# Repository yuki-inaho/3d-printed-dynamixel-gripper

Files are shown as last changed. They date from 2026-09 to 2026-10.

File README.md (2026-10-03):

# 3D Printed DYNAMIXEL Gripper

**2026-10-03 P05改善:** [コネクタ通過窓の局所候補と検査](studies/p05-cable-20261003/README.md)。
凍結V2のコピーへ5.5×10.2 mm・角R0.5の左右窓を反映し、穴と実ケース座面を保持。
モーター取付前の公称コネクタ通過は確認、装着後は後カバー干渉が残る。実物組付け・製作は未承認。
[10手順のグリッパ組立マニュアル](docs/gripper-assembly-20261003/MANUAL.md)には画像・ねじ長さ・個数表を収録。

**2026-09-26取り込み:** [低配置D405のレビュー・OCCT 8再実行](docs/D405_LOW_PROFILE_INTAKE.md)。
俯角30°・爪20 mm延長のV2候補と改善検証器を取り込み、固定Pixi環境でwheel再ビルド・再変換した。
新規URDFと12 STLは受領モデルと全バイト一致。製作承認はfalse。

現行候補: **ID5だけでPG3を開閉、下流の追加モーターなし**。
`outputs/pg3-id5-only-r1/`へ全腕3開度STEP/三面図を生成。原本保持、実機装着DoDは未達。
仕様は[ID5単独開閉](docs/PG3_ID5_ONLY_DESIGN.md)、実行記録は
[Sep24作業書](temp/workdoc_Sep24-2026_pg3_id5_only.md)。

旧r5履歴: **P06局所改修・側方カメラホルダ・取付ねじ候補の6台構成**。
P06/frame干渉240.5625→0 mm3、 nominal離隔0.5 mm。側面4穴だけφ2.8へ変更し、
実相手M06 CADの穴軸・ねじ深さを照合。実機装着・印刷DoDはまだ未達です。
r4ではPG3フレーム端部4箇所だけに0.3 mmの逃げを追加。元部品を再構成せず、
取付穴・主レール・mask外の材料を保持しています。r5では寸法を変えずにクランクの
B-rep生成手順を修正し、simulationも改修済み実組立の形状を使用します。統合CAD/画像/
運動学は`outputs/pg3-installable-candidate-r5/`。r4補足検査は履歴でありr5へ自動継承しません。
[実機装着の受入状況と未確定条件](docs/INSTALLATION_READINESS.md)を参照してください。
[旧r5の設計契約・締結・組立順・再現方法](docs/PG3_INSTALLATION_CANDIDATE.md)は履歴です。
[以前の無改修取込結果](docs/PG3_C9_INTEGRATION.md)は比較用の履歴です。

2026-09-23再監査: **全DoD達成の宣言は撤回**。ラック案は歯・案内・固定が未実装の概念図。
PG2 R5 (縦置きXL430、クランク+2リンク、印刷ガイド) を別候補として追加しました。
[辛口レビュー・2方式の現状と改善順](docs/REVIEW_PG2_AND_SELF_AUDIT.md)を先に参照してください。

2026-09-24の要求は、**全XL430・ロール不要・平行グリッパ**です。
ID5だけで開閉・追加モーターなしに確定。旧r5は最新要求の完成形ではありません。
[新設計仕様](docs/PG3_ID5_ONLY_DESIGN.md)と
[作業書](temp/workdoc_Sep24-2026_pg3_id5_only.md)に沿って検証中です。
カメラ未購入、28x28 mm四穴を維持。最新希望はID5モーターケース角ねじ付近を使い、
モーター上方から把持域を斜め下向きに見る構成です。旧P05側方案は受入候補ではありません。
詳細は[新カメラ取付要求](docs/CAMERA_MOUNT_ID5_CORNER.md)と
`specs/camera_mount_id5_corner.yaml`を参照。把持物は寸法未定のキューブ。
P05局所配線逃げ候補の検討は許可済みですが、CADは製作承認ではありません。
コード位置と再現用CAD入力は[カメラ設計コード索引](docs/CAMERA_MOUNT_CODE_INDEX.md)にまとめています。

- [カメラジグの設計・検証・組立順序](docs/CAMERA_JIG.md)
- [全XL430末端の現状と検証結果](docs/ALL_XL430_TERMINAL_STATUS.md)
- [BOM草稿](docs/BOM_DRAFT.md)
- [組立・合成校正・実機校正の手順](docs/ASSEMBLY_AND_CALIBRATION.md)
- [未解決事項と再開条件](docs/OPEN_ISSUES.md)
- [他エージェントの横開きグリッパ・カメラ案のレビューと改善方針](docs/REVIEW_LATERAL_20260922.md)
- カメラCAD: `outputs/camera-jig-20260922-r11/`。
- 全XL430末端CAD: `outputs/terminal-all-xl430-20260922-r3/`。
- MuJoCo/AprilTag E2E: `outputs/calibration-demo-20260923-r4/`。
- いずれも **UNVALIDATED/診断候補。印刷・実カメラ校正・運用承認ではない。**

```bash
rtk proxy uv sync --locked
rtk proxy env MUJOCO_GL=egl uv run pytest -q -n auto --dist loadgroup   # 並列（推奨）
rtk proxy env MUJOCO_GL=egl uv run pytest -q                              # 逐次（同じテスト集合）
rtk proxy env MUJOCO_GL=egl uv run python -m scripts.review_pg3_installation \
  --out outputs/pg3-install-next
rtk proxy uv run python -m scripts.review_pg3_guide_relief outputs/pg3-install-next \
  --out outputs/pg3-install-next-audit/guide_relief
```

並列実行の振り分けは `tests/conftest.py` が決める（モジュール単位、重いモジュールは分割、合成キャリブレーションは1回生成）。
繰り返し解析するSTEPは `.pytest_cache` の内容アドレス型キャッシュから読む（`CAD_STEP_CACHE_DIR=` で無効化）。
i7-9750H（6コア/12スレッド）で719件: 12並列約1分50秒、6並列約2分15秒、逐次約5分30秒（変更前14分06秒）。12並列の最小空きメモリ約9 GB。
内訳と判断は [テスト実行時間の記録](docs/TEST_PERFORMANCE.md)。検証対象・閾値は逐次実行と同一。

現在の生成・監査は未達項目を残すためexit 2。正常終了や描画だけを印刷承認にしません。
原本01_frame/07_crankのコピーは参照用で、r5の部品選択は`review.json`のreplacement mapに従います。

以前のカメラ単体・校正デモを再現する場合 (現PG3統合版とは別):

```bash
rtk proxy uv run python -m camera_jig.build --out outputs/camera-jig-next
rtk proxy uv run python -m camera_jig.serviceability outputs/camera-jig-next
rtk proxy env MUJOCO_GL=egl uv run python scripts/run_calibration_demo.py \
  --config specs/simulation_calibration.yaml \
  --out outputs/calibration-demo-next
```

出力先は未使用のrun名にする。`camera_jig.serviceability`は、装着状態でカメラねじへ工具が
入らないことを検出してexit 2になる。先付け工程の結果は同JSON内で別に記録する。
静的合格を可動域・強度・配線・印刷承認へ読み替えない。

PG2の入力検証・独立STEP検査 (元ソースは実行しない):

```bash
rtk proxy uv run python -m scripts.review_pg2 import \
  outputs/PG2_XL430_upright_printed_guide_R5.zip --out references/pg2-r5
rtk proxy uv run python -m scripts.review_pg2 review \
  --source references/pg2-r5/PG2_XL430 --out outputs/pg2-next --render
```

この環境では取込済み。importは既存ディレクトリを上書きしません。
reviewは全腕未適合・未解決を理由にexit 2。JSONと画像は残し、成功扱いで印刷へ進めません。
方式台帳: `specs/gripper_variants.yaml`。最新診断: `outputs/pg2-independent-20260923-r2/`。
旧E2E r4は履歴であり、コード変更後のSHA再検証で不一致になることは正常です。

## 構成

- `camera_jig/`: P05固定カメラジグの生成/検証コード。
- `gripper_design/`: 全XL430 interface、平行ジョー概念、末端assembly、締結/工具契約。
- `simulation/`: 座標変換、AprilGrid、MuJoCo EGL描画、検出、校正、CAD連携。
- `tests/`: 正常・不良対照の回帰検査。
- `references/arm-r3/`: 写真のリンクに対応するR3入力。変更禁止。
- `references/robonine/`: SO101参考カメラ取付とライセンス。
- `skills/`: プロジェクト内のコピー。PlaywrightはCADスキルと独立。
- `references/arm-baseline/`, `references/prior-checkpoint/`: 別形状・旧調査。今回の取付元と混同しない。
- `docs/HANDOFF.md`, `REQUIREMENTS.md`, `DESIGN_BASIS.md`, `INTERFACES.md`,
  `CAD_PDCA.md`: 初期引継ぎ資料。PG3最新状態は`PG3_INSTALLATION_CANDIDATE.md`を優先する。
- `outputs/`, `temp/`: Git対象外。検証結論はdocsにも記録。

Python 3.12 + uv。GitHubリポジトリは`yuki-inaho/3d-printed-dynamixel-gripper`。
CAD作業中の実機通電・通信・モーター制御は行わない。

## Onshape取り込み・検証・URDFの保存点

[2026-09-26の成果と手順](studies/onshape-20260926/README.md)。短縮D405候補の公開V2、URDF、スクリーンショット付きマニュアル、作業記録を保存。次の低位置カメラ・爪延長設計の比較基準です。

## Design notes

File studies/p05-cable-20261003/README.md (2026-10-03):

# P05コネクタ通過窓の局所改善候補

2026-10-03。ユーザーの「コネクタ付きでも通せる寸法」という条件に合わせ、
凍結Onshape V2のP05左右窓を **5.5×10.2 mm、四隅R0.5 mm** に変更した。
Chili3Dで確認したコピーを保存し、元V2、他261部品、モーターケースは保持した。
実物組付けと製作は未承認。**コネクタの窓通過はモーター取り付け前の診断であり、
取り付け後にコネクタを直線で抜き差しできる判定ではない。**

## 成果物

- [統合STEP](CAD/V2_P05_CABLE_CLEARANCE_CANDIDATE.step)
- [P05単体STEP](CAD/P05_CABLE_CLEARANCE_CANDIDATE.step) / [STL](CAD/P05_CABLE_CLEARANCE_CANDIDATE.stl)
- [P05単体の窓](images/view-support.png)、[右側とモーター](images/view-motor-right.png)、[左側とモーター](images/view-motor-left.png)、[支持の斜視](images/view-oblique.png)
- [CAD検査結果](evidence/review.json)、[静的接触走査](evidence/contacts.json)、[装着後コネクタ通過の診断](evidence/plug-with-motor-diagnostic.json)
- [全262部品の保持照合](evidence/unchanged-occurrences.json)、[Chili3D読込・入力SHA](evidence/browser-p05-cable-check-20261003.json)
- [保存後のSHA・文書リンク・ブラウザ検査](evidence/final-verification.json)
- [グリッパ組立マニュアル](../../docs/gripper-assembly-20261003/MANUAL.md) / [PDF](../../docs/gripper-assembly-20261003/MANUAL.pdf)
- [設計判断・検証記録](WORKLOG.md)、[保存ファイルのSHA](MANIFEST.json)

## 寸法と変更範囲

単位mm。窓中心は元V2 world座標Y=151.15、Z=178.7。
左右の既存側壁を貫通し、側壁厚4 mm、内側面X=-14.45/+14.05は移動しない。

| 項目 | 元V2 | 改善候補 |
|---|---:|---:|
| 配線窓の幅Y×高さZ | 3×8 | 5.5×10.2、角R0.5 |
| 仮線φ1.9からP05までの最小距離 | 0.55 | 1.65 |
| 仮線から後カバーまでの最小距離 | 0.25 | 0.25 |
| EHR-3公称筐体の窓通過（モーターなし） | 干渉56.126 mm³/側 | 最小距離0.35 |
| ケースを挟む内側面間隔 | 28.5 | 28.5 |
| 実ケースとの接触面積（各側） | 942.005 mm² | 同じ材料セット、lost/added=0 |
| 元の円筒穴面 | 18 | 18、位置・径・範囲を保持 |
| 窓mask外／保護領域の材料損失 | — | 0 / 0 mm³ |
| 局所除去体積 | — | 270.535 mm³ |

検査に用いたEHR-3筐体断面は9.5×3.8 mm、通過向きは9.5をZ、3.8をYに合わせる。
高さ6.5と別の0.6突出を含む保守的な軸方向包絡を使った。
実ケーブルのロック部・被覆・曲げ制限・造形公差は未確認であり、この公称値を実物保証にしない。
配線診断はPCBから内部で90度曲げ、側方へ直線で出す仮経路である。
PCBヘッダーの軸方向に後カバーを貫く経路は採用していない。

## 組付けの条件と残る問題

モーターが入る前にコネクタをP05窓へ通すことを候補の前提とする。
先配線したモーター全体の挿入軌跡は未検証なので、実行済みの組立手順として扱わない。
モーターを置いた状態でコネクタを側方へ直線移動すると、左右とも後カバーと約29.43 mm³干渉する。
このFAILは窓を広げた結果にも残る。カバーを削る／外したまま使う解決は行っていない。

P05・仮線・全保存相手を除外なしで走査した1848組は **1841 PASS / 1 ERROR / 6 UNKNOWN**。
ERRORは`088:ARM_M04_ref00`の供給B-repのBoolean自己対照不成立、UNKNOWNは仮線6本と
非solidの`152:ARM_M05_ref05`の重なり。これらを組付けPASSへ読み替えない。
装着後プラグ診断524組は **518 PASS / 2 FAIL / 2 ERROR / 2 UNKNOWN**。
FAILは`157:ARM_M05_ref06`後カバー、ERRORは`143:PG3_XL430_fixed`、UNKNOWNは同非solid参照。

接触面保持は締付け荷重・支持強度・印刷嵌合の合格ではない。
実ハーネス、曲げ、ストレインリリーフ、ねじと工具、先配線モーター挿入、全腕可動中の配線は未確認。
CADのM05ラベルと実機ID5の対応観測も未確定のまま。

## 入力と再現

入力は[凍結V2 STEP](../low-profile-20260926/outputs/low-profile-250g/CAD/final-version.step)。
SHA-256: `9f58c947753e9229b30939da23ce4c87c1cc85eeb39372518de4ffb98991b93f`。
[元Onshape V2](https://cad.onshape.com/documents/29e8557c76e89bcf64f50566/v/f6162b4adc88af9d07f1194a/e/d5415bf725ba822741b01703)を変更せず、
XCAFのP05だけをコピー上で置換した。Onshapeクラウド文書、URDF、G-codeは更新していない。
262 occurrenceの名前・階層・配置を保持し、他261部品の形状署名を照合した。
この署名検査を不良B-repの完全な材料集合同等性の証明にはしない。

```bash
rtk proxy uv run --no-sync python -m scripts.review_p05_cable_clearance --out outputs/p05-cable-next
rtk proxy uv run --no-sync pytest -q tests/test_p05_cable_relief.py tests/test_p05_cable_clearance.py
rtk proxy uv run --no-sync ruff check gripper_design/p05_cable_clearance.py scripts/review_p05_cable_clearance.py tests/test_p05_cable_clearance.py
```

変更対象の既存9＋新規14＝23試験PASS。全リポジトリのsuiteは未実行。
STEP再読込のP05材料対照、単体STLの閉じた1成分、実ケースのtrim済み面接触を検査した。
CAD依存版はreview.jsonと既存uv.lockに記録している。
公式経路は[ROBOTIS XL430組立説明](https://emanual.robotis.com/docs/en/dxl/x/xl430-w250/#idler-horn-assembly)、
公称コネクタ寸法は[JST EHデータシート](https://www.jst-mfg.com/product/pdf/eng/eEH.pdf)を参照した。

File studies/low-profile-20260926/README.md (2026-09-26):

# 低位置D405・爪延長スタディ

**今回の取り込み:** [レビュー・Pixi/OCCT 8再実行](../../docs/D405_LOW_PROFILE_INTAKE.md)。
固定lockからwheelを再ビルド・再変換し、保存V2との全バイト一致を確認した。
個人パスを除いたテキストと新しいSHA一覧は `integration/` を参照。
以下の「今回」は受領した各記録の実行時点を指す。

**引き継ぎ継続:** [検証器改善・実STEP再検証](revalidation/README.md)。
旧D6/D7を保存証跡として監査し、52試験と独立STEP再読込を追加した。
CAD/URDF形状は未変更。以下の35試験は前回の記録であり、今回の52件と混同しない。
`revalidation/` を保存範囲に追加した。元の327件一覧は同ディレクトリのINPUT-SNAPSHOT-MANIFESTに保持する。

2026-09-26、俯角30°、爪+20 mm、D405ガラス中心(-0.2,165,235) mmを選定。旧75°候補に比べカメラ高さは12.40 mm低い一方、250 gとカメラ等の部分モーメントは9.45%増える。V2から新規URDFを生成し、441閉路と11native姿勢を検証した。実物の耐久性・材料・造形・校正は未確認。

- [20ページ操作マニュアルPDF](outputs/low-profile-250g/MANUAL.pdf) / [画像拡大可能なHTML](outputs/low-profile-250g/MANUAL.html) / [設計比較レポート](outputs/low-profile-250g/REPORT.md)。
- [最終URDFと再現方法](outputs/low-profile-250g/robot/README.md)、[作業書](outputs/low-profile-250g/WORKDOC.md)、[保存情報](outputs/low-profile-250g/DELIVERY.md)。
- [公開Onshape V2](https://cad.onshape.com/documents/29e8557c76e89bcf64f50566/v/f6162b4adc88af9d07f1194a/e/d5415bf725ba822741b01703)：左右パッドの所属を修正した版。
- [設計選定](outputs/low-profile-250g/SELECTION.md)、[UI検証](outputs/low-profile-250g/NATIVE-VALIDATION.md)、[出力記録](outputs/low-profile-250g/EXPORT.md)。
- [変換器](https://github.com/yuki-inaho/urdf_from_step/tree/codex/pixi-occt8)：commit `1b2cea3`、Pixi + OCCT 8.0.1、13回帰試験PASS。新モデルのFK/負対照4件とCAD18件を合わせ35試験PASS。
- [リポジトリ直下skills/の4スキル](../../skills/ONSHAPE-WORKFLOW.md)：Onshapeの実証知見、write/review/startと全参照ファイルを保存。

`CAD/final-version.step` が修正版V2の入力。`diagnostics/v1-pad-misassigned` は負の証拠として保存した旧失敗例であり、製作用データではない。標準UI URDF ZIPも旧V1の参考出力である。

保存範囲は `outputs/low-profile-250g` と `work/low-profile` のみ。SHA256は `SNAPSHOT-MANIFEST.json`。秘密情報の既知パターンをZIP内も含め検査し、ブラウザプロファイル、認証状態、HTTPキャッシュ、bytecodeは含めない。スクリプトは当時のディレクトリ構造と元リポジトリのuv環境に依存するため、コピーだけで全操作を再実行できる独立パッケージとはしていない。UI更新スクリプトを公開保存版へ無条件に再実行しない。

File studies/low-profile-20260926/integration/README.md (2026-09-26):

# 今回の取り込み・Pixi/OCCT 8追試

[取り込みレビュー](../../../docs/D405_LOW_PROFILE_INTAKE.md) と [verification.json](verification.json) が
今回の記録。隣の `revalidation/` は受領した別エージェントの記録であり、別実行として保持する。

## 元環境の追試

repo rootから実行する。Linux用の固定lockを使い、既存の出力を上書きしない。
以下の変換はCADファイルを読み、ローカルファイルを作る。Onshapeへのアクセスは不要。
Git取得と依存パッケージの取得にはネットワークが必要。

```bash
RUN=$(mktemp -d temp/d405-occt8-XXXXXX)
CONVERTER="$RUN/converter"
BASE=studies/low-profile-20260926/outputs/low-profile-250g
rtk proxy git clone --single-branch --branch codex/pixi-occt8 https://github.com/yuki-inaho/urdf_from_step.git "$CONVERTER"
rtk proxy git -C "$CONVERTER" checkout --detach 1b2cea31c56b875bf98c1d65084781322f5fc835
rtk proxy pixi install --manifest-path "$CONVERTER/pixi.toml" --locked
rtk proxy pixi run --manifest-path "$CONVERTER/pixi.toml" --locked versions
rtk proxy pixi run --manifest-path "$CONVERTER/pixi.toml" --locked test
rtk proxy pixi run --manifest-path "$CONVERTER/pixi.toml" --locked build
PY="$CONVERTER/.pixi/envs/default/bin/python"
rtk proxy "$PY" -I -m pip install --no-deps "$CONVERTER/dist/urdf_from_step-0.2.0-py3-none-any.whl"
rtk proxy "$PY" -I -m urdf_from_step "$BASE/CAD/final-version.step" --config "$BASE/robot/converter-config.json" --output "$RUN/model"
rtk proxy uv run --no-sync python "$BASE/robot/replay_step.py" --output "$RUN/replay"
rtk proxy "$PY" "$BASE/robot/validate_robot.py" --model "$RUN/model" --native "$RUN/replay/native-pose-transforms.json" --output "$RUN/verification.json"
```

`python -I` でソースツリーのPYTHONPATHを除外し、インストールしたwheelを用いて変換する。
kernelはPixiのOCCT 8.0.1配布バイナリであり、OCCTソース自体の再コンパイルではない。
CadQuery/OCPで行うSTEPの独立読込はrepoのuv環境を使う。
CLIの生ログには環境のパスが出るため、`RUN` はGit対象外に置く。

## 証跡の読み方

- `verification.json`: D6保存監査・D7実行の区別、archive SHA、kernel/wheel情報、結果、未確認項目。
- `kinematics.json`: 新規OCCT 8変換と今回の独立STEP再読込の照合。
- `native-pose-transforms.json`: 今回の11姿勢の独立読込から作った入力。
- `converter-tests.xml`: 今回の変換器13試験。
- `robot-tests.xml`: 取り込み・修正後の改善版52試験。
- `cad-tests.xml`: 保存検査補強後の20試験。変更前の18件に2件追加。
- `geometry-preservation.json`: 保存された実V2の爪/パッドとR5原本の照合。
- `artifact-equality.json`: 新規URDF/config/12 STLと受領した最終V2の全バイト一致。
- `quality.json`: lint・プライバシー照合と、既存19ファイルの整形不一致。
- `manifest.json`: 共有可能な取り込みファイルの最終SHA。元manifestの代わりに検査する。

取り込み時にテキストの個人パスを除去したため、元の `SNAPSHOT-MANIFEST.json`、
`INPUT-SNAPSHOT-MANIFEST.json`、旧XML/JSON内のSHAは原本に対する履歴である。
元bundleは取り込み前に1599件の全ファイル照合がPASSした。原本はGit対象外で保管する。
このディレクトリのログも個人パスを除いた写しであり、バイト同一の生ログとは呼ばない。

生成モデルは受領モデルと全バイト一致したため、同じ大きなSTLを二重にGitへ追加しない。
新規生成モデル・wheel・生ログ・各姿勢の完全inventoryはローカルの
`temp/intake_d405_20260926/occt8-original/` に残す。

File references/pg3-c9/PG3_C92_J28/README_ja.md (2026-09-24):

# C92-J28 — 小型の駆動部に、把持面の広い爪を組み合わせる改訂

版: PG3-C92-XL430-J28-C9 / 作成: 2026-09-23

**CAD上の試作検査を完了。印刷・実組立・摩擦・把持力・強度・摩耗は未検証です。**

## 変更の要点
前案は全奥行62 mmを優先し、爪と接触パッドを短くしすぎました。今回は本体の小型化を維持し、爪の前方への張り出しと連続した把持面を増やしました。

| 寸法 | C7 | C92-J28 |
|---|---:|---:|
| 全幅 | 92 mm | 92 mm |
| 全高 | 63.25 mm | 63.25 mm |
| 爪の前後長 | 12.1 mm | 28 mm |
| 爪の高さ / 板厚 | 36 / 5 mm | 36 / 5 mm |
| パッドの高さ×奥行×厚さ | 28×3×1 mm | 28×20×1 mm |
| 案内シューの移動方向の長さ | 14 mm | 18 mm |
| 最大開口（左右1 mmパッド込み） | 48.895 mm | 48.895 mm |
| 閉位置の開口 | 0.927 mm | 0.927 mm |
| サーボ背面から爪先まで | 61.8 mm | 77.7 mm |

爪は単純に拡大していません。穴位置・座面をそのままに、根元へ補強リブを追加し、把持面の貫通窓をなくしました。パッド全域に5 mm厚の裏打ちがあります。
上下のシューは中央側へ4 mm延長しました。クランクを避けるため、延長部分の内縁には0.5 mmの逃げを設けています。閉じ位置の左右スライダ最短距離は1.927 mmです。

## 変更しないもの
単一XL430-W250の背面直立配置、枠、押さえ、クランク、リンク、ホーンスペーサー、元の締結品と穴位置です。金属の案内棒・別体の金属カラー・直動軸受はありません。通常ねじ・ナット・座金は既存どおり使用します。カメラと全腕接続は対象外です。

## 納品内容
- CAD/C92_J28_open.step、mid.step、closed.step: 名称付き組立CAD。世界Xが開閉、Zが上、-Yが前です。
- STL/changed_parts/: 左右スライダと左右爪の4個。すべて各1個です。
- STL/unchanged_C7/: 基本形状を変更していない残りの部品。新規製作時は全部で9種類11個です。
- CAD/parts/: 部品STEP。これは構築座標であり、印刷姿勢や組立移動位置とは別です。
- REVIEW_ja.html、docs/: 設計・作業・組立・現物受入資料。
- reports/: この版で実行した結果。iterations/C8には距離不足で不合格だった前段の記録。
- source/: 再生成と検査。reference/C7は使った旧版ソースとサーボ模型であり、現物保証ではありません。

## 実行したCAD検査
56件の旧版形状・配置照合、1,101点の運動拘束式、25〜135°を0.5°刻みで221姿勢の全組立干渉、45姿勢の変更部接近距離を確認しました。不許可の交差体積が0.01 mm³を超える組合せは0件です。指定嵌合・同一剛体群の締結を除いた、変更部を含む組合せの最小測定距離は0.400 mmです。クランクと延長シューには95〜125°を0.1°刻みで追加検査しました。
工程別挿入9経路・工具軸18件、標準9 STL・3組立STEPの再読込みが合格です。6種類の意図的な誤形状も拒否しました。
10/25/45 mm幅の箱と直径25 mmの円柱が両パッドに接触し、前方の経路で他部品と交差しないことを検査しました。把持面全域の裏打ちも体積で検査しています。これは物体保持の試験ではありません。

## 荷重をどう扱ったか
爪が長いほど同じ力でも案内部へのモーメントが増えます。5 N/爪を仮の計算点とすると、パッド中央で旧約107.5 Nmmから新139.5 Nmmへ増えます。先端寄りでは189.5 Nmmです。
支持長を内側へ延ばして荷重を受ける距離を広げましたが、それで摩擦・強度が保証されるわけではありません。reports/load_review.jsonの反力・摩擦・単純梁の値は、明記した仮定による計算例です。実測の材料特性や摩擦係数を使った有限要素解析ではありません。5 Nは耐荷重でも定格でもありません。
接触面が広いことは、保持力が面積比例で増えるという意味ではありません。設計の目的は、物を差し込む深さと接触位置の選択肢を確保することです。

## 再生成
requirements.txtの環境を用意し、source/rebuild.pyを実行します。旧版のレポートを再利用せずにCAD・検査・画像・レビューを再生成します。実機へ指令を送るコードは含みません。

## 出典と区別
元の機構構成は会話中のMini Max作例を参照しました。今回の28 mm、18 mm、78 mm上限はこの改訂の設計判断であり、元記事の寸法ではありません。
案内の荷重点・支持間隔について参考にしたメーカー説明は igus「The 2:1 Rule and How to Define Fixed and Floating Bearings」です。その製品固有の2:1数値を、この印刷ガイドの合格基準として移植していません。
https://www.igus.com/company/linear-guides-the-2-1-rule-ca
サーボの制御情報: https://docs.robotis.com/docs/dxl/model_reference/x_series/xl_series/xl430-w250/

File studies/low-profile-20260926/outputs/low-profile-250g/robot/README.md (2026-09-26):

# V2 STEPから生成した運動学モデル

**継続作業の改善:** [52試験と独立STEP再読込](../../../revalidation/README.md)。
`validate_robot.py --model outputs/model --output outputs/new/report.json` で対象を明示できる。
引数なしでは保存modelを検査して標準出力へ表示し、下記の過去validation.jsonは上書きしない。
`replay_step.py --output outputs/new/replay-directory` がSTEP本体を再読込する。
元のPixi/OCCT8変換と、今回のCadQuery/OCP独立検査は別の実行記録である。

- 最終URDF: [model/robot.urdf](model/robot.urdf)、12 STLは [model/assets](model/assets)。一式を同じ相対配置で扱う。
- 関節設定: [converter-config.json](converter-config.json)、元のUI定義 [joint-definitions.json](joint-definitions.json)。
- 閉路の従属計算: [pg3_states.py](pg3_states.py)。`python pg3_states.py 25` で開、90で中立、135で閉。
- 照合: [validation.json](validation.json)、[validate_robot.py](validate_robot.py)、[test_validation.py](test_validation.py)。
- 再現環境・コマンド: [CONVERTER.md](../CONVERTER.md)。Pixi + OCCT 8.0.1、ROSなしで実行。

16リンク/15関節、5能動+4受動+6固定。閉路は左右それぞれ2つの固定補助frameの位置一致で検証する。441状態と11 native姿勢を照合済み。入力は `../CAD/final-version.step`（V2、SHA256 `9f58c947753e9229b30939da23ce4c87c1cc85eeb39372518de4ffb98991b93f`）。部品262件を12メッシュへ新規変換した。

このモデルは運動学用。effort/velocity=0は未設定であり、コントローラ設定として使わない。質量/慣性、実機ホーム、カメラ外部校正、物理エンジン用collision形状は未確定。`onshape-native/` は修正前V1の比較用出力で、最終モデルではない。

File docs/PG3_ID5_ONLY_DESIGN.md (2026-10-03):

# ID5単独開閉 PG3 設計仕様

2026-10-03局所候補: [P05コネクタ通過窓](../studies/p05-cable-20261003/README.md)。
凍結V2コピーで左右窓5.5×10.2 mm・角R0.5、既存穴と実ケース座面を保持。
ユーザー条件はコネクタ付き通過。モーター取付前の公称筐体通過だけを確認し、
装着後の後カバー干渉、先配線モーター挿入、実物対応・製作ゲートは未達のまま。
下記の支持・配線・締結要求を置き換えない。

更新: 2026-09-24。状態: 設計・検証中、製作未承認。
作業手順と実績は `temp/workdoc_Sep24-2026_pg3_id5_only.md`。
本書は「何をどの構造で満たすか」を定義し、実行済み判定とは分ける。

## 1. 目的と確定要求

既存全XL430アームへPG3平行グリッパとカメラを装着できる状態にする。
ID5のXL430-W250-T一台で開閉する。手首ロール用の別モーターや追加ID6は使わない。
既存ID1〜4を消したり、ロール機構を残して単にソフト固定する解釈は採用しない。
カメラは未購入、SO101参考と同じ28x28 mm四穴を維持する。最新要求はID5モーターの
ケース角ねじ付近で支持し、モーター上方から把持域を斜め下向きに見ること。
旧P05側方マウントは視点が意図に合わず、新候補の採用案ではない。
対象は寸法/重量未定のキューブ。10/20/30 mmは比較用提案であり確定仕様ではない。
P05の局所配線逃げ候補と再印刷案は許可済み。原本/穴/締結・接触面/支持機能を保持。
付属M2.6x5ねじはない/不明。型番/頭/ねじ山/先端/有効深さを検証せず代用品を決めない。
実印刷・SD書込・通電・シリアル操作・購入は本作業では行わない。

## 2. 旧設計との相違

| 項目 | 旧r5 | 新候補 |
|---|---|---|
| ID5の役割 | ロール候補 | 開閉専用、ユーザー確定 |
| 末端駆動台数 | ロールと開閉の2台 | 開閉の1台 |
| PG3配置 | CAD M06位置 | CAD M05位置を幾何候補とする |
| P06/元P07 | P06局所改修を保持 | 下流モーターと共に撤去候補 |
| P05 | 未変更 | 支持機能維持、必要な配線逃げだけを別版で検討 |
| カメラ | P05固定の側方支持 | ID5モーターケース角ねじ付近に支持する頭上・斜め下向き候補 |
| 可動評価 | 追加ロール±30度を含む | ID4等上流姿勢と開閉。独立ロールなし |

ユーザーが確定したのは役割と台数。CADのM05という文字列が実機ID5の実測証拠にはならない。
次節の配置は新設計の採用候補であり、非通電実物照合ゲートは残す。
元r5を上書きせず、新しい出力ディレクトリと部品台帳を使用する。

## 3. 座標・配置契約

単位mm。アームは `references/arm-r3/arm_XL430_R3.step` の保存world座標。
PG3内部座標はX=開閉方向、Y=機構上方、Z=出力軸/指の延長方向。
候補変換は `world = Rx(-90deg) * local + (-0.2,164.9,164.6)`。
これによりZ出力軸はworld +Y、爪の開閉方向Xはworld Xになる。
供給モーターSTEPをこの変換で置き、元M05_ref00に有限形状署名を照合する。
さらに実取付穴/座面を照合する。署名一致だけで完全材料同等性やboltabilityを承認しない。

部品帰属契約:
- M01〜M04とP01〜P05等の上流部品は保存する。
- M06配下全要素、P06、P07を新候補の撤去台帳へ記録する。原本からは削除しない。
- M05_ref00はPG3のfixed/horn分割表示へ置換する。他のM05参照は原位置で保持する。
- 分割fixed/hornの2 CAD要素は物理モーター1台。隠れた2台目を許容しない。
- 新カメラ候補はID5モーターの固定ケース側へ支持し、開閉ホーンには固定しない。
  ケース角ねじが適切な取付点かは未確認。元CADのM05ラベルも実機ID5との観測照合を証明しない。
- 角度はPG3機構角25〜135度。実XL430絶対角/ホーム値との対応は未確定。

## 4. 支持・配線・締結

新配置ではID5ケースをP05が支持し、出力ホーンがPG3クランクを駆動する。
PG3フレームはケースに固定する。原P05とフレームの干渉があれば、P05の支持を
削って通すのではなく、重複する固定構造・ねじ・荷重経路から再設計する。
無断の支持幅変更や嵌合面移動、旧P06を非表示にするだけの浮遊組立は禁止。

配線は公式ケース出口/中空軸を起点とする。ケーブル断面/曲げ径は実品未確定。
既存のOD1.9/R1.2診断は製品保証値でなく、これだけで最小窓寸法を決めない。
窓候補ごとに変更mask・除去体積・保護面・最小残断面・丸み・組付順を記録する。
case cover内部の交差はP05を削っても解消しないため別扱いとする。
挿抜/先配線/最終配線状態/開閉時の屈曲を分離して検査する。
支えの連結性はCAD、PLA強度/クリープは荷重/材料/印刷条件と実物で検証する。

初期配線窓の比較候補: 左右の厚4mm側壁のみ。X[14.05,18.05]と[-18.45,-14.45]を
貫通し、YZ平面で中心線Y151.0、端部中心Z176.2/181.2、端部R1.5の丸長穴。
窓の幅3.0/全高8.0mm。旧診断OD1.9に対する側壁通過の名目隙間は0.55mm。
これは曲げ許容/プラグ通過/実ケーブルの最小寸法決定ではない。
穴中心群と元穴外周2.5mmの保護環、Y144.4以下のクランプ/連結板を切除しない。
原motor接触面の変化と荷重成立は別評価する。切除率だけで強度合格にしない。
この候補を新アームへ自動採用せず、単体・全体差分・配線残交差を保存する。
初案Y150.6は仮ケーブルがmotor rear coverに6箇所交差したため棄却。
Y151.0は線径/曲率/モーターを変更せず、側方脚と窓位置だけ0.4mm移動する候補。
仮ケーブル対カバーの公称隙間0.25mmを別検査する。実ケーブルの曲げ許容は未確認。

## 5. カメラと対象

取付ピッチは28x28 mm四穴で、基板外形やFOVではない。旧仮FOV50度は診断限定。
視点はID5ケース角ねじ付近の支持から、モーター上方を通して把持域へ斜め下向きに向ける。
角度や突き出し量は未決で、CAD上の視野比較を先に行う。旧P05側方位置を少し動かすだけで
要求を満たしたとしない。カメラの型番・実外形・光学中心・FOV・重量はnullのまま扱う。
キューブの実寸未定なのでまず10/20/30 mmの比較画像と遮蔽物帰属を出す。
画像に一画素でも見えることを実用可視性としない。キューブと指、パッドの遮蔽を分ける。
取付位置変更はカメラ実体/ホルダ/工具/ケーブルも追従させる。仮想センサだけを移動しない。
ケース角ねじの用途、ねじ長/有効かかり/ケース締結維持、頭への工具アクセス、組立順と
カメラケーブル経路を同じ候補版で調べる。これらが未解決なら取付・印刷承認を出さない。
候補型番/焦点/質量は `docs/CAMERA_SELECTION.md`。未購入でも設計作業は継続する。

## 6. 実装境界

新規 `gripper_design/pg3_id5.py` が配置/帰属を担当する。
`scripts/review_pg3_id5.py` が保存・再読込・対検査・画像・証跡を担当する。
既存 `gripper_design/pg3.py` の運動学と `pg3_crank_representation.py` の修正を再利用。
旧配置の `pg3_installation.py` は再現用として残す。
`simulation/pg3_scene.py` は既存配置を既定値として保ち、明示的なno-roll配置を追加する。
変更後のPG3実体を逆変換してmesh化し、元neutral形状へ暗黙に戻さない。
新sceneにはwrist_roll jointを作らない。非ゼロroll入力は拒否する。

## 7. 検証と受入

| 契約 | 負例 | 正例の証拠 | 合格の限界 |
|---|---|---|---|
| ID5単独 | 旧r5/残M06/ID6要求 | 数量・帰属・撤去台帳と5モーター構成 | 実機ID照合は別 |
| 座標 | 誤軸/1mmずれ | M05形状署名/穴中心/座面 | 材料同等性・締結別 |
| 原形保存 | 保護面侵入/余分な穴 | mask外差分0、単一正体積solid | 強度別 |
| 干渉 | 元干渉形状/配置ずれ | 全変更部品対全相手、ERROR/UNKNOWN保持 | 接触/公差別 |
| 運動 | stale mesh/残roll joint | 保存版mesh、開閉閉ループ/台数 | 力学別 |
| 可視性 | 指による対象隠れ | headless画像/segmentationと同一版DOM | 実optics別 |

DoDは要求書D-01〜10。部分検査が緑でも実機装着完了にはしない。
製作可能なBOM/全締結・工具・配線・強度・画像/仕様照合・非通電実物組付けが必要。
全体の未達を残したまま診断成果を出せるが、製作リリースは禁止。

## 8. 現チェックポイント

`outputs/pg3-id5-only-r1/`: P05未変更の5モーター設計配置。3開度各257要素、
変更部品対全相手16965対は16920PASS/35ERROR/10UNKNOWN。保存版/全体/XYZ画像あり。
M06/P06/P07撤去とM05の分割表示置換を台帳化。r5BOM/sceneは転用禁止。

`outputs/pg3-id5-p05-windows-r2/`: 上記midへ局所窓P05を入れた比較候補。
単体STEP/STLと組立STEPを保存。切除176.548668mm3、mask外/保護域損失0、18円筒穴面保存。
仮線はP05側0.55mm/未加工カバー側0.25mmの隙間、線相互15対も検査。
窓+線の相手検査は1806PASS/1ERROR/6UNKNOWN、FAILなし。ただし未承認。
ERRORはP05対M04_ref00、UNKNOWNは線対M05_ref05表面参照。消去・無視しない。
旧窓r1はカバー交差6件を含む不採用履歴。

関連70試験成功。新no-roll simulation、視野改善、全締結・配線・強度・現物は未完。
診断線のOD1.9/R1.2は仮定。現物ケーブルやねじを発注済みとは扱わない。

2026-09-24の可視化チェックポイント: `outputs/pg3-id5-p05-windows-r2/ID5_mid_P05_windows_CANDIDATE.step`
をChili3D v0.7.0-betaで全体表示。専用headless Playwright DOMにはARM_M01〜M05、PG3 57 labels、
CAMERA 21 labels（`CAMERA_REFERENCE_UNCONFIRMED`を含む）があり、M06/P06/P07はなかった。
STEP SHA256 `102031f3b4b2adda6d3126ffe890a6dc082a65aa07df59f7cfc0674bc48f35a8`はr2 review output hashと一致。
斜視/+X/+Y/+Zスクリーンショットは`outputs/pg3-id5-chili3d-20260924/`に保存。
consoleは0 errors/10 warnings。これは固定mid姿勢の可視化であり、組立承認ではない。
同候補は1806 PASS/1 ERROR/6 UNKNOWNで、配線・製作承認はfalseのまま。

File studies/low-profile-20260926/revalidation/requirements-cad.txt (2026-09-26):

# Independent STEP replay, not the archived pythonocc/OCCT8 converter.
-r requirements-kinematics.txt
cadquery==2.8.0
cadquery-ocp==7.9.3.1.1

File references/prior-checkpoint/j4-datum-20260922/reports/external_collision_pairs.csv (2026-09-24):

left | right | left_unit | right_unit | volume_mm3
KEEP_057_shoulder_rotation_1 | J6_XL430_00_DC11_A01_DUMMY_1 | /Robot Arm v14/servo connector angle v4:1/shoulder_rotation:1 | /Robot Arm v14/XL,XC-330 v1:8 | 1039.2954431023497
KEEP_057_shoulder_rotation_1 | J6_XL430_02_=>[0_1_1_6] | /Robot Arm v14/servo connector angle v4:1/shoulder_rotation:1 | /Robot Arm v14/XL,XC-330 v1:8 | 6.031857894892397
KEEP_057_shoulder_rotation_1 | J6_XL430_12_=>[0_1_1_18] | /Robot Arm v14/servo connector angle v4:1/shoulder_rotation:1 | /Robot Arm v14/XL,XC-330 v1:8 | 13.934250010216415
KEEP_058_connector_1 | J4_XL430_00_DC11_A01_DUMMY_1 | /Robot Arm v14/XL430 to XL330 new connector v6:1/connector:1 | /Robot Arm v14/XL,XC-330 v1:7 | 2827.8558552196755
KEEP_058_connector_1 | J4_XL430_03_B3B-EH_1 | /Robot Arm v14/XL430 to XL330 new connector v6:1/connector:1 | /Robot Arm v14/XL,XC-330 v1:7 | 12.62115036213913
KEEP_058_connector_1 | J4_XL430_06_=>[0_1_1_10] | /Robot Arm v14/XL430 to XL330 new connector v6:1/connector:1 | /Robot Arm v14/XL,XC-330 v1:7 | 25.606698763296947
KEEP_116_moving_side_1 | J5_GRIPPER_XL430_00_DC11_A01_DUMMY_1 | /Robot Arm v14/gripper v9:1/moving side:1 | /Robot Arm v14/gripper v9:1/XL,XC-330 v1:1 | 934.6458119326501
KEEP_116_moving_side_1 | J5_GRIPPER_XL430_02_=>[0_1_1_6] | /Robot Arm v14/gripper v9:1/moving side:1 | /Robot Arm v14/gripper v9:1/XL,XC-330 v1:1 | 6.031857894892441
KEEP_116_moving_side_1 | J5_GRIPPER_XL430_12_=>[0_1_1_18] | /Robot Arm v14/gripper v9:1/moving side:1 | /Robot Arm v14/gripper v9:1/XL,XC-330 v1:1 | 5.779241043317275
KEEP_116_moving_side_1 | J5_GRIPPER_XL430_31_DC11_A01_SPACER_DUMMY_5 | /Robot Arm v14/gripper v9:1/moving side:1 | /Robot Arm v14/gripper v9:1/XL,XC-330 v1:1 | 1.1848876513328777
KEEP_117_static_side_1 | J3_XL430_00_DC11_A01_DUMMY_1 | /Robot Arm v14/gripper v9:1/static side:1 | /Robot Arm v14/XL,XC-330 v1:6 | 3507.948456876133
KEEP_117_static_side_1 | J3_XL430_02_=>[0_1_1_6] | /Robot Arm v14/gripper v9:1/static side:1 | /Robot Arm v14/XL,XC-330 v1:6 | 6.03185789489239
KEEP_117_static_side_1 | J3_XL430_12_=>[0_1_1_18] | /Robot Arm v14/gripper v9:1/static side:1 | /Robot Arm v14/XL,XC-330 v1:6 | 14.72621556370212
KEEP_117_static_side_1 | J3_XL430_14_=>[0_1_1_18] | /Robot Arm v14/gripper v9:1/static side:1 | /Robot Arm v14/XL,XC-330 v1:6 | 14.726215563702114
KEEP_117_static_side_1 | J5_GRIPPER_XL430_00_DC11_A01_DUMMY_1 | /Robot Arm v14/gripper v9:1/static side:1 | /Robot Arm v14/gripper v9:1/XL,XC-330 v1:1 | 4601.819076957151
KEEP_117_static_side_1 | J5_GRIPPER_XL430_04_B3B-EH_2 | /Robot Arm v14/gripper v9:1/static side:1 | /Robot Arm v14/gripper v9:1/XL,XC-330 v1:1 | 47.24529757293747
KEEP_117_static_side_1 | J5_GRIPPER_XL430_06_=>[0_1_1_10] | /Robot Arm v14/gripper v9:1/static side:1 | /Robot Arm v14/gripper v9:1/XL,XC-330 v1:1 | 51.374180767441025
KEEP_117_static_side_1 | J5_GRIPPER_XL430_07_DC11_A01_IDLER_DUMMY_1 | /Robot Arm v14/gripper v9:1/static side:1 | /Robot Arm v14/gripper v9:1/XL,XC-330 v1:1 | 0.667183166875737
KEEP_117_static_side_1 | J5_GRIPPER_XL430_14_=>[0_1_1_18] | /Robot Arm v14/gripper v9:1/static side:1 | /Robot Arm v14/gripper v9:1/XL,XC-330 v1:1 | 12.192716173747472
KEEP_117_static_side_1 | J5_GRIPPER_XL430_20_=>[0_1_1_18] | /Robot Arm v14/gripper v9:1/static side:1 | /Robot Arm v14/gripper v9:1/XL,XC-330 v1:1 | 48.78936383005846
KEEP_117_static_side_1 | J5_GRIPPER_XL430_32_DC11_A01_SPACER_DUMMY_6 | /Robot Arm v14/gripper v9:1/static side:1 | /Robot Arm v14/gripper v9:1/XL,XC-330 v1:1 | 35.834295150394084
KEEP_160_connector_1 | J4_XL430_00_DC11_A01_DUMMY_1 | /Robot Arm v14/XL330_to_XL330_straight v5:1/connector:1 | /Robot Arm v14/XL,XC-330 v1:7 | 1097.2250677645184
KEEP_160_connector_1 | J4_XL430_02_=>[0_1_1_6] | /Robot Arm v14/XL330_to_XL330_straight v5:1/connector:1 | /Robot Arm v14/XL,XC-330 v1:7 | 1.3253902695033797
KEEP_160_connector_1 | J4_XL430_14_=>[0_1_1_18] | /Robot Arm v14/XL330_to_XL330_straight v5:1/connector:1 | /Robot Arm v14/XL,XC-330 v1:7 | 9.822900909798452
KEEP_160_connector_1 | J6_XL430_00_DC11_A01_DUMMY_1 | /Robot Arm v14/XL330_to_XL330_straight v5:1/connector:1 | /Robot Arm v14/XL,XC-330 v1:8 | 5706.17826050467
KEEP_160_connector_1 | J6_XL430_16_=>[0_1_1_18] | /Robot Arm v14/XL330_to_XL330_straight v5:1/connector:1 | /Robot Arm v14/XL,XC-330 v1:8 | 10.44790479820554
KEEP_160_connector_1 | J6_XL430_18_=>[0_1_1_18] | /Robot Arm v14/XL330_to_XL330_straight v5:1/connector:1 | /Robot Arm v14/XL,XC-330 v1:8 | 6.911763390878769
KEEP_160_connector_1 | J6_XL430_24_=>[0_1_1_18] | /Robot Arm v14/XL330_to_XL330_straight v5:1/connector:1 | /Robot Arm v14/XL,XC-330 v1:8 | 48.752479715959815
KEEP_160_connector_1 | J6_XL430_26_=>[0_1_1_18] | /Robot Arm v14/XL330_to_XL330_straight v5:1/connector:1 | /Robot Arm v14/XL,XC-330 v1:8 | 33.16819994217889
KEEP_160_connector_1 | J6_XL430_33_DC11_A01_SPACER_DUMMY_7 | /Robot Arm v14/XL330_to_XL330_straight v5:1/connector:1 | /Robot Arm v14/XL,XC-330 v1:8 | 51.58992469504882
KEEP_160_connector_1 | J6_XL430_34_DC11_A01_SPACER_DUMMY_8 | /Robot Arm v14/XL330_to_XL330_straight v5:1/connector:1 | /Robot Arm v14/XL,XC-330 v1:8 | 59.91043322446404
J3_XL430_00_DC11_A01_DUMMY_1 | J5_GRIPPER_XL430_00_DC11_A01_DUMMY_1 | /Robot Arm v14/XL,XC-330 v1:6 | /Robot Arm v14/gripper v9:1/XL,XC-330 v1:1 | 9608.813106768863
J3_XL430_00_DC11_A01_DUMMY_1 | J5_GRIPPER_XL430_04_B3B-EH_2 | /Robot Arm v14/XL,XC-330 v1:6 | /Robot Arm v14/gripper v9:1/XL,XC-330 v1:1 | 107.0299388206695
J3_XL430_00_DC11_A01_DUMMY_1 | J5_GRIPPER_XL430_06_=>[0_1_1_10] | /Robot Arm v14/XL,XC-330 v1:6 | /Robot Arm v14/gripper v9:1/XL,XC-330 v1:1 | 169.26827375125123
J3_XL430_00_DC11_A01_DUMMY_1 | J5_GRIPPER_XL430_07_DC11_A01_IDLER_DUMMY_1 | /Robot Arm v14/XL,XC-330 v1:6 | /Robot Arm v14/gripper v9:1/XL,XC-330 v1:1 | 168.34047125212308
J3_XL430_00_DC11_A01_DUMMY_1 | J5_GRIPPER_XL430_08_DC11_A01_IDLER_CAP_DUMMY_1 | /Robot Arm v14/XL,XC-330 v1:6 | /Robot Arm v14/gripper v9:1/XL,XC-330 v1:1 | 17.004389080643666
J3_XL430_00_DC11_A01_DUMMY_1 | J5_GRIPPER_XL430_10_=>[0_1_1_15] | /Robot Arm v14/XL,XC-330 v1:6 | /Robot Arm v14/gripper v9:1/XL,XC-330 v1:1 | 5.1754210332760575
J3_XL430_00_DC11_A01_DUMMY_1 | J5_GRIPPER_XL430_16_=>[0_1_1_18] | /Robot Arm v14/XL,XC-330 v1:6 | /Robot Arm v14/gripper v9:1/XL,XC-330 v1:1 | 10.121475219088085
J3_XL430_00_DC11_A01_DUMMY_1 | J5_GRIPPER_XL430_24_=>[0_1_1_18] | /Robot Arm v14/XL,XC-330 v1:6 | /Robot Arm v14/gripper v9:1/XL,XC-330 v1:1 | 57.737185485291064
J3_XL430_00_DC11_A01_DUMMY_1 | J5_GRIPPER_XL430_34_DC11_A01_SPACER_DUMMY_8 | /Robot Arm v14/XL,XC-330 v1:6 | /Robot Arm v14/gripper v9:1/XL,XC-330 v1:1 | 97.90115604598681
J3_XL430_02_=>[0_1_1_6] | J5_GRIPPER_XL430_07_DC11_A01_IDLER_DUMMY_1 | /Robot Arm v14/XL,XC-330 v1:6 | /Robot Arm v14/gripper v9:1/XL,XC-330 v1:1 | 1.9852430778198749
J3_XL430_12_=>[0_1_1_18] | J5_GRIPPER_XL430_07_DC11_A01_IDLER_DUMMY_1 | /Robot Arm v14/XL,XC-330 v1:6 | /Robot Arm v14/gripper v9:1/XL,XC-330 v1:1 | 13.74225765729494
J3_XL430_14_=>[0_1_1_18] | J5_GRIPPER_XL430_00_DC11_A01_DUMMY_1 | /Robot Arm v14/XL,XC-330 v1:6 | /Robot Arm v14/gripper v9:1/XL,XC-330 v1:1 | 53.01532108790955
J3_XL430_27_DC11_A01_SPACER_DUMMY_1 | J5_GRIPPER_XL430_07_DC11_A01_IDLER_DUMMY_1 | /Robot Arm v14/XL,XC-330 v1:6 | /Robot Arm v14/gripper v9:1/XL,XC-330 v1:1 | 14.325443390236419
J3_XL430_27_DC11_A01_SPACER_DUMMY_1 | J5_GRIPPER_XL430_08_DC11_A01_IDLER_CAP_DUMMY_1 | /Robot Arm v14/XL,XC-330 v1:6 | /Robot Arm v14/gripper v9:1/XL,XC-330 v1:1 | 32.78384766296821
J3_XL430_28_DC11_A01_SPACER_DUMMY_2 | J5_GRIPPER_XL430_00_DC11_A01_DUMMY_1 | /Robot Arm v14/XL,XC-330 v1:6 | /Robot Arm v14/gripper v9:1/XL,XC-330 v1:1 | 97.90115604598681

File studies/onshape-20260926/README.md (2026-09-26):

# Onshape作業の保存点（2026-09-26）

**取り込み注記:** 本文は元作業の履歴。今回のテキスト写しは個人の絶対パスを除去した。
元manifestは原本用として保持し、取り込み版は
[`verify_d405_intake.py`](../../scripts/verify_d405_intake.py) で照合する。
アカウント表示を含むUI画像とHTML/PDF/ZIPはローカル保持・Git対象外。
現在の候補と再現結果は [取り込みレビュー](../../docs/D405_LOW_PROFILE_INTAKE.md) を参照。

ユーザー指示「一旦commit & push」に基づき、爪延長・低位置カメラの再設計に入る前の成果を保存した。

- [最新版の短縮D405可動モデルとURDF](outputs/optimization-250g/robot/README.md)
- [設計比較レポート](outputs/optimization-250g/REPORT.md)
- [スクリーンショット付き操作マニュアル](outputs/optimization-250g/MANUAL.md) / [PDF](outputs/optimization-250g/MANUAL.pdf)
- [作業書と完了監査](outputs/optimization-250g/WORKDOC.md)
- [初回・独立再作成の成果物一覧](outputs/README.md)

この保存点は俯角75°の候補C_y185_z250_p75である。「最良」は当時の既存爪形状・中央40°以上の探索内での選定を指し、参考Robonineの30°や爪延長を含む全体最適を証明していない。新しいユーザー指示は爪延長も許可しており、その再設計は本保存点以降に別作業書で扱う。

## 保存範囲

outputsはユーザー向け成果物。workのPythonは実行時のコード、motion/onshapeのJSONは非秘密のAPI観測証跡。元CADリポジトリのコードや参照形状は上書きしていない。SNAPSHOT-MANIFEST.jsonに全保存ファイルのSHA256を記録した。APIキー、Cookie、ブラウザプロファイル、HTTPキャッシュ、ダウンロードしたメーカーPDF、bytecodeは収録しない。

この作業は元々Git外の独立ディレクトリで行われたため、スクリプトには当時の絶対パスと作業ディレクトリ構造が残る。読み取り専用の検証はnumpy/trimesh環境で `outputs/optimization-250g/robot/validate_robot.py` を実行できる。CAD再生成には本リポジトリのuv環境とPYTHONPATHが必要。Onshape更新には自分の認証設定と新規文書stateが必要であり、記録済みの公開版IDへ再度書き込まない。

旧robot bundle ZIPは旧R5用。最終短縮候補はoptimization-250g/robotであり、取り違えない。250g連続運転、実機耐久性、材料・造形・ホーム校正は未確認の運動学モデルである。

GitではSTEP/STLを生成CADデータとしてbinary扱いにし、原文ライセンスと旧マニュアルの末尾空行だけを個別に許容した。CADや原文のSHAを変える空白除去はせず、他の文書・コードは通常のgit diff --check対象とする。

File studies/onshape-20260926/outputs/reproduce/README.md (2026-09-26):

# 再現スクリプト

今回のD405 R5 STEPに固有の部品分類と座標を使う。別ロボットへ流用するときは分類・軸・原点・制限を再測定する。

1. Onshapeで新しいpublic Documentを作成し、`source-manifest.json` のSTEPをアップロードする。入力と版を記録。
2. STEP translationがDONEになってから、262ボディを含む統合Part Studioと空のAssemblyのIDを取得する。取り込みが複数タブを生成しても、同名の小部品Part Studioを選ばない。
3. この実行専用のstateフォルダを作り、`project.example.json`を`project.json`として配置し4IDを入力する。stateを別ドキュメントに使い回さない。
4. 以下の環境変数を設定する。鍵は画面や履歴へ直接貼らず、利用環境の秘密値管理方法で読み込む。

```text
ONSHAPE_TASK_WORK    専用stateフォルダの絶対パス
ONSHAPE_TASK_OUTPUT  この再実行の出力先の絶対パス
ONSHAPE_ACCESS_KEY   公式APIキーのaccess key
ONSHAPE_SECRET_KEY   公式APIキーのsecret key
```

```bash
python3 bootstrap.py
python3 build_composites.py
python3 setup_assembly.py
python3 build_joints.py
python3 set_pose.py 25 open
python3 set_pose.py 135 closed
python3 set_pose.py 90 mid
```

各段階は成功分をJSON ledgerへ保存する。途中の通信失敗ではOnshape側の作成状態とledgerを照合してから再実行する。stateにはAPIカウンタを置く。これはexporterや他ツールの呼出しを含まないため、公式Developer画面の利用量も確認する。

ネイティブ検証は `../VALIDATION_GUIDE.md` に従う。成功後にVersionを保存し、`../robot/config.json` を新規出力フォルダへコピーしてurlをそのVersionへ変更する。環境変数は同じ状態で、別途インストールした `onshape-to-robot==1.8.3` を実行する。

```bash
onshape-to-robot outputs/new_robot_output
```

エクスポータの未加工URDFは既定の `package://assets/...` とゼロ慣性を含む。今回の利用版への変換内容は成果物READMEに記載している。元の未加工出力も残す。今回の `pg3_states.py` と `validate_robot.py` を使う場合は、関節名・フレーム・軸が同一であることを先に確認する。

このスクリプト群の主要処理は2回の実モデル作成で使用済み。配布版の差分はID設定・秘密値を環境変数へ切り出したことと、stateを別projectへ誤用しないための照合処理。スクリプトだけでネイティブ干渉検出を代替するものではない。

## 利用版への整形

新規出力フォルダに対し `python3 make_portable.py outputs/new_robot_output` を実行する。今回のno_dynamics、16リンク／15関節の構成専用。初回の未加工URDFを保持し、相対メッシュ参照・不要要素の除去を適用する。再エクスポートには別フォルダを使う。スクリーンショット付きの全手順は `../manual/MANUAL.html` または `../manual/MANUAL.pdf` を参照。

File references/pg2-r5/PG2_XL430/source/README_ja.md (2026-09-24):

# 再生成と検査

検査環境はPython 3.13、依存版はrequirements.txtの通りです。別のOSや版では幾何判定が変わる可能性があります。寸法単位はmmです。

主形状はdesign.py、カメラはcamera.py、隙間選択品・試験片はcalibration.pyです。design.pyのParametersはこの試作の凍結仕様です。parameters_frozen.jsonは記録用の写しで、自動入力ファイルではありません。モーター取付やガイドのすべての寸法を任意に変更できる汎用設計器と呼ぶものではありません。

依存パッケージを入れた環境で、PG2_XL430フォルダから以下を実行します。

```
python source/check_frame_roundtrip.py
python source/build_release.py
python source/engineering_checks.py
python source/check_saved.py
python source/validate_worker.py 0 30 57
python source/validate_worker.py 1 58 85
python source/validate_worker.py 2 86 113
python source/validate_worker.py 3 114 140
python source/check_camera_delta.py
python source/make_previews.py
python source/release_gate.py
python source/make_report.py
python source/release_gate.py --seal
python source/release_gate.py --verify-manifest
```

validate_worker.pyを並列実行する場合はRAMを確認してください。4並列での実行を使用しましたが、メモリ不足の場合は上のように順番に実行できます。VTKの画像生成は画面なしで行います。

最終版は本体R5＋カメラC3です。最終111姿勢試験はこの組合せを対象にしています。途中のR4/C1/C2の結果はreports/iterationsへ分け、現行版の試験に読み替えません。

guardrails.pyは型番、実際のケース姿勢、実際の出力軸、短い爪、左右対称、金属軸禁止、ケースねじ深さ、非接続印刷品などを検査します。意図的に違反させた12例が拒否されることも検査します。結果が不合格なら、期待値や許容干渉リストだけを変更して通さず、形状・仕様へ戻って修正します。

出力STLは面の向きや破損を自動修復しません。STL形式が持つ重複頂点を座標で統合してトポロジーを検査するだけです。保存STEPは再読込み後の形状だけでなく、組立内の部品間も検査します。前段の検査を通過しても、こちらで不一致が出たら公開を止めます。

参考モーターはreference/内の添付由来データを読みます。extract_reference.pyとprobe_servo.pyは入力抽出の記録で、元アーカイブの場所を前提にしています。通常の再生成には実行不要です。サーボのダミー形状は表示用に出力部と本体へ分けています。内部部品の設計・性能検証はしません。

reports/iterations/には失敗・中断・旧形状が残ります。これらを最終版として印刷しません。製作用の唯一の出力場所はSTL/、最終の組立形状はCAD/です。preview画像・GIFは実CAD由来で、実験動画ではありません。

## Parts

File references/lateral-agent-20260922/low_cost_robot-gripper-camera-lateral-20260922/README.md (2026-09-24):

# Low-Cost Robot Arm
Join the waitlist here to get all the parts in one package: https://tau-robotics.com/robots

This repository contains the files to build and control a low-cost robot arm that costs about $250. You can also build a second robot arm (the leader arm) to control the other arm (the follower arm) that costs about $180, for a total of $430. The design of the leader is inspired by the [GELLO project](https://github.com/wuphilipp/gello_mechanical) but is simpler to build. Such a robot arm is well suited for [robot learning](https://x.com/alexkoch_ai/status/1756500716854841835?s=20). Two of those arms are also capable of [folding clothes](https://x.com/alexkoch_ai/status/1772750496174149708?s=20).

This robot arm uses Dynamixel XL430 and Dynamixel XL330 servo motors. The XL430 motors are almost twice as strong and are used for the first two joints.
The XL330 motors are weaker but weigh only 18g each. This makes the arm very lightweight and fast.
Dynamixel sells the U2D2 adapter to connect the servos to a computer. However, this is very expensive and the latency is very high. This build uses another cheaper adapter board instead.
The robot arm can be controlled with the Dynamixel SDK: ```pip install dynamixel-sdk```

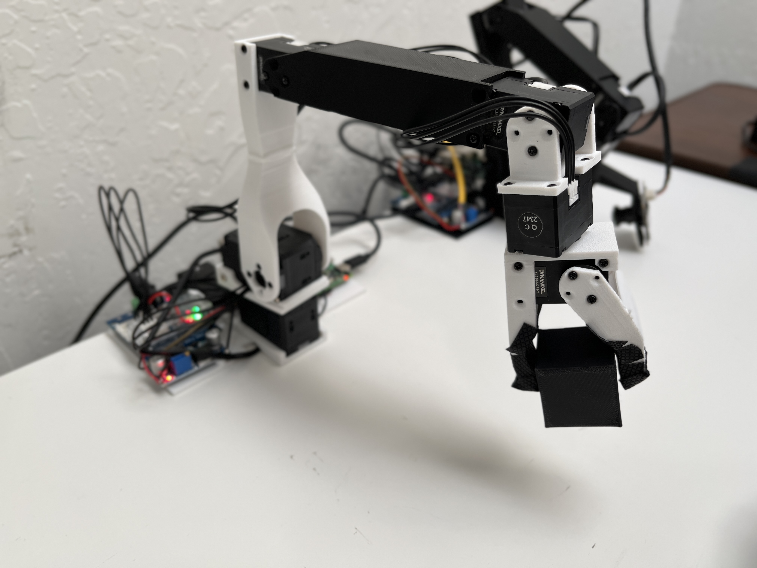
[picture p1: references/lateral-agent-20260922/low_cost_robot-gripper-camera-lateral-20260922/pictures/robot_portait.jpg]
Robot Arm


## Follower Arm

### Required Materials

| Part | Cost | Buying link | Specs |
|---|---|---| --- |
| 2x Dynamixel XL430-W250 | $100 | https://www.robotis.us/dynamixel-xl430-w250-t/ | https://emanual.robotis.com/docs/en/dxl/x/xl430-w250/ |
| 4x Dynamixel XL330-M288 | $96  | https://www.robotis.us/dynamixel-xl330-m288-t/ | https://emanual.robotis.com/docs/en/dxl/x/xl330-m288/|
| XL330 Idler Wheel | $10  | https://www.robotis.us/fpx330-h101-4pcs-set/ | **Note**: pack of four; three needed for  longer version pictured above (with elbow-to-wrist extension), two needed for shorter version shown in the [assembly video](https://youtu.be/RckrXOEoWrk)|
| XL430 Idler Wheel | $7 | https://www.robotis.us/hn11-i101-set/ | |
| Waveshare Serial Bus Servo Driver Board | $10  | https://a.co/d/7C3RUYU | |
| Voltage Reducer | $10 | https://a.co/d/cy02ADW | **Note**: pack of six, only one needed per follower arm |
| 12V Power Supply | $12  | https://a.co/d/40o8uMN | |
| Table Clamp | $6 | https://a.co/d/4KEiYdV | |
| Wires | $7 | https://a.co/d/hQfk2cb | |
| Total | $258 | | |

There is usually a 10% discount code for the Robotis shop. It might also help to add some grip tape to the gripper (e.g. https://a.co/d/dW7BnEN). A USB-C cable is necessary to connect the servo driver board to a computer.

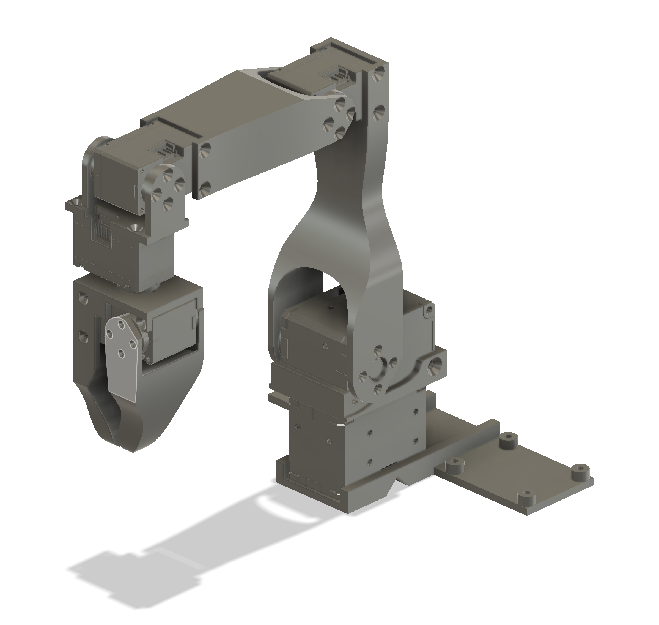
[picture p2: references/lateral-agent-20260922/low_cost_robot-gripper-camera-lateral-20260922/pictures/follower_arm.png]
follower


### Assembly

Video of the assembly: https://youtu.be/RckrXOEoWrk

1. Print all parts with a 3D printer
   1. The STL files are in `hardware/follower/stl`
   2. The parts are designed to be easy to print; only the moving part of the gripper needs supports
2. Scanning motors
   1. Connect the driver board to a computer (should work with Linux and MacOS)
   2. Figure out the device name (e.g. tty.usbmodem57380045631 for MacOS): ```ls /dev/tty.*```
   3. Scan each motor individually with [Dynamixel Wizard](https://emanual.robotis.com/docs/en/software/dynamixel/dynamixel_wizard2/)
      1. Set the baudrate to 1M for all motors
      2. Set the servo IDs to 1 for the shoulder to 5 (6 if using the elbow-to-wrist extension) for the gripper servo
3. Assembly
   1. Assemble the arm without the base
      1. Make sure that the servos are fixed in the same position as in the CAD
      2. The servo horn should be in the default position when screwed in
   2. Solder wires onto voltage reducer; input should be connected to female connectors and the output to male connectors
   3. Screw the voltage reducer and the servo driver board onto the base
   4. Screw the base onto the arm
   5. Connect D, V, and G ports on the driver board to the shoulder rotation servo
   6. Connect the shoulder rotation servo to the shoulder lift servo
   7. Connect the input for the voltage reducer to V and G ports on the driver board
   8. Connect the output of the voltage reducer and the remaining D port of the driver board to the elbow servo
   9. Connect the driver board to the power supply
   10. Connect to an XL330 servo and view the input voltage on Dynamixel Wizard, then adjust the screw on the voltage reducer until the input voltage is 5V

## Leader Arm

### Required Materials

| Part | Cost | Buying link | Specs |
|---|---| --- | --- |
| 6x Dynamixel XL330-M077 | $144 |  https://www.robotis.us/dynamixel-xl330-m077-t/ | https://emanual.robotis.com/docs/en/dxl/x/xl330-m077/|
| XL330 Frame | $7 | https://www.robotis.us/fpx330-s101-4pcs-set/ | |
| XL330 Idler Wheel | $10  | https://www.robotis.us/fpx330-h101-4pcs-set/ | **Note**: pack of four; three needed for longer version (with elbow-to-wrist extension), two needed for shorter version pictured below |
| Waveshare Serial Bus Servo Driver Board | $10  | https://a.co/d/7C3RUYU | |
| 5V Power Supply | $6 | https://a.co/d/5u90NVp | |
| Table Clamp | $6 | https://a.co/d/4KEiYdV | |
| Total | $183 | | |

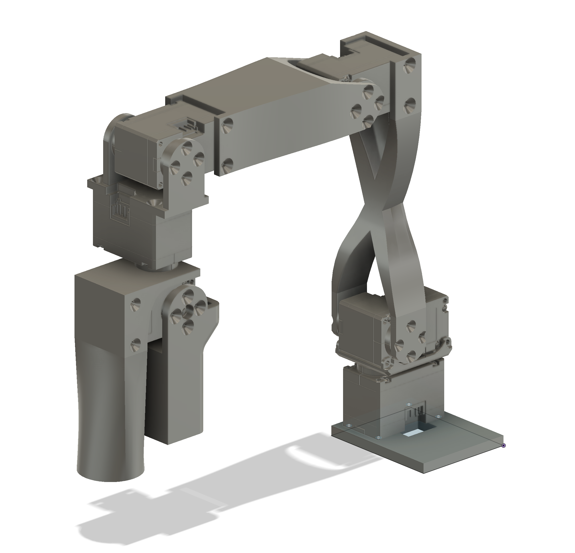
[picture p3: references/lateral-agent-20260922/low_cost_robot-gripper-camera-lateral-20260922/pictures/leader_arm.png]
leader


### Assembly

The assembly of the leader arm is simpler since all motors use 5V. The gripper is replace by a handle and a trigger. During use, a small torque can be applied to the trigger so that it opens by default. The GELLO design uses a spring for this purpose but it is much more difficult to assemble.
The `teleoperation.py` script can be used to test the arms. However, the device names might have to be adjusted.

## Simulation
A basic simulation environment in MuJoCo is available by running `simulation.py`.

## 横開きグリッパ＋手首カメラ（2026-09-22）

既存ジョーを90°組み替え、交換式UVC28カメラマウントを追加する検証用プロトタイプ。混在サーボ版が基準で、実機製作は未承認です。実装・組立案は [study README](skills/cad-reverse-parametric/studies/gripper_camera_lateral/README_ja.md)、検証結果は [設計レビュー](docs/gripper_camera_lateral_20260922.md)、作業記録は [diary](diary/2026-09-22_gripper-camera-lateral.md) を参照してください。

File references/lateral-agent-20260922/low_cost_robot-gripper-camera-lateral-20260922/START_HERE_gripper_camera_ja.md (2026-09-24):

# 横開きジョー＋カメラマウント — 納品ファイル

**幾何検証付きの試作設計です。実機製作は未承認です。**

最初に [画像付きレビュー](skills/cad-reverse-parametric/outputs/gripper_camera_lateral/unaccepted/20260922-r1/review_ja.html) をブラウザーで開いてください。外部通信なしで表示でき、閉じ／25°／50°のカメラ視点を切り替えられます。

- [設計と組立案](skills/cad-reverse-parametric/studies/gripper_camera_lateral/README_ja.md)
- [検証結果](docs/gripper_camera_lateral_20260922.md)
- [作業記録](diary/2026-09-22_gripper-camera-lateral.md)
- [手首近傍STEP・50°開き](skills/cad-reverse-parametric/outputs/gripper_camera_lateral/unaccepted/20260922-r1/CAD/hand_50deg.step)
- [全腕STEP・50°開き](skills/cad-reverse-parametric/outputs/gripper_camera_lateral/unaccepted/20260922-r1/CAD/full_arm_50deg.step)
- [新規3部品のSTEP/STL](skills/cad-reverse-parametric/outputs/gripper_camera_lateral/unaccepted/20260922-r1/CAD/parts/)

基準は混在サーボ版（XL430×2＋XL330系×4）です。全XL430版の未解決干渉を承認していません。既存ジョーは固定指＋回転指の機構を維持し、形状を作り替えず手首で90°組み替えています。

カメラ型番、実画角、実ねじ長・有効ねじ深さ、強度、実配線、全関節の動作・実機校正が未確認です。特に4 mmフランジ追加によるねじ長の変更を現物で確定してください。カメラ・サーボを含むアセンブリSTEPを一体印刷しないでください。STLは新規3部品だけの検討用で、造形方向・材料・スライス条件は未承認です。

GitHubへのpush／PR作成は行っていません。変更対象は元ZIPに対する `delivery_manifest.json` を参照してください。元の `hardware/` の全ファイルはバイト単位で保存しています。

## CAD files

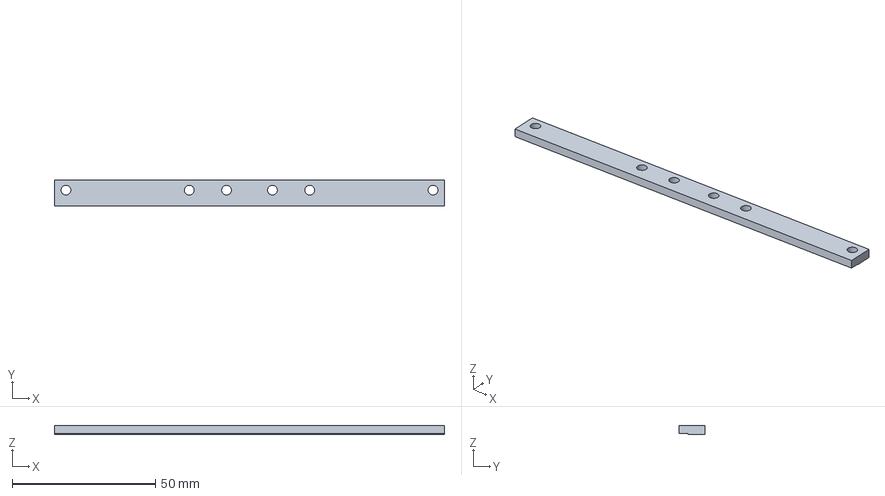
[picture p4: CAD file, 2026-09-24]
references/pg2-r5/PG2_XL430/CAD/parts/02_retainer_total_gap_0p9.step
136.0 x 9.00 x 3.00 mm

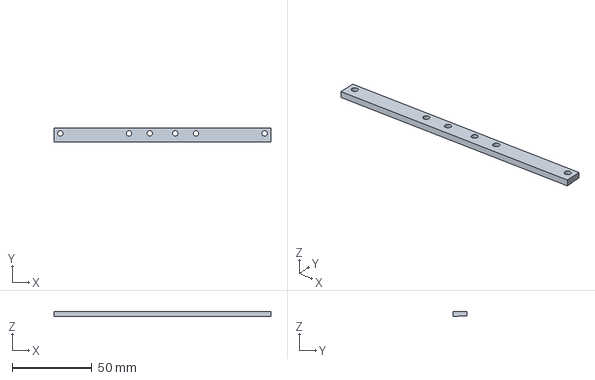
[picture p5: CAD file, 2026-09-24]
references/pg2-r5/PG2_XL430/CAD/parts/02_retainer_total_gap_0p5.step
136.0 x 9.00 x 3.20 mm

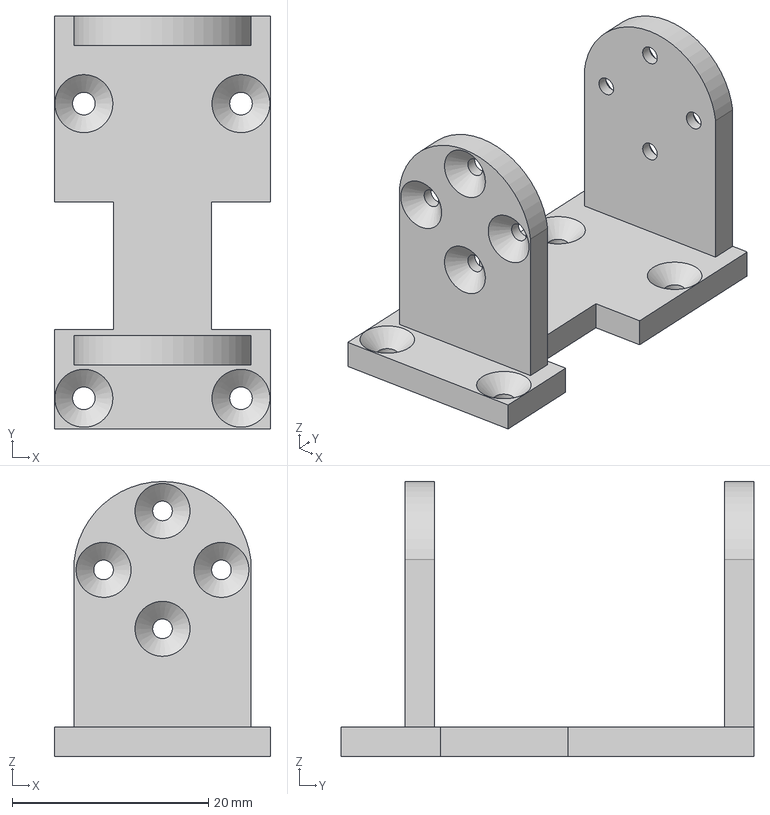
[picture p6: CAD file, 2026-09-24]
references/arm-baseline/step/elbow_to_wrist.step
22.0 x 42.0 x 28.0 mm

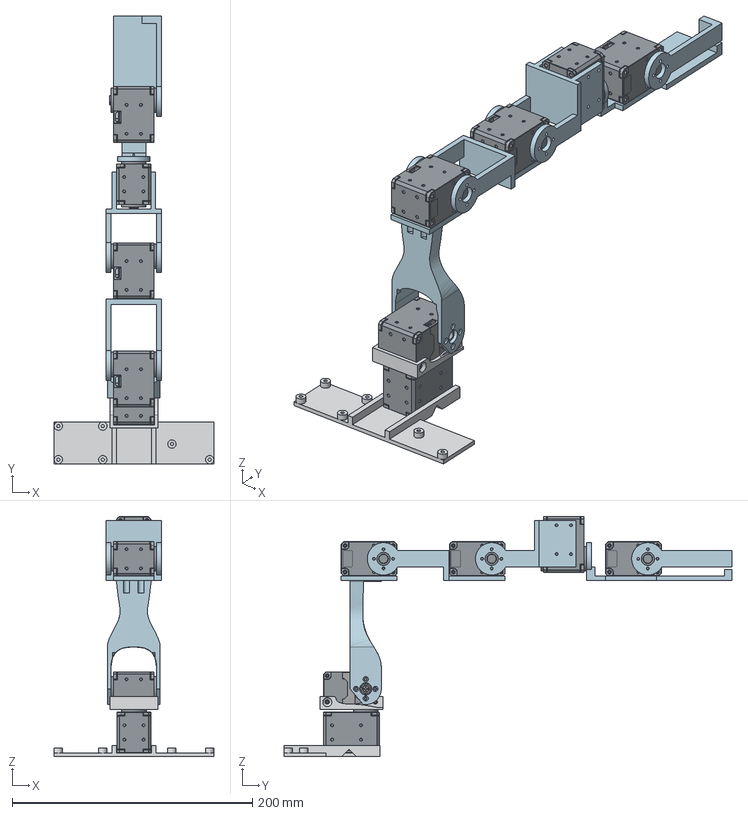
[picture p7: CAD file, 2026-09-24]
references/arm-r3/arm_XL430_R3.step
133.0 x 372.9 x 199.8 mm
M01_ref00 x 6
M01_ref01 x 6
M01_ref02 x 6
M01_ref03 x 6
M01_ref04 x 6
M01_ref05 x 6
M01_ref06 x 6
M01_ref07 x 6
M01_ref08 x 6
M01_ref09 x 6
M01_ref10 x 6
M01_ref11 x 6
M01_ref12 x 6
M01_ref13 x 6
M01_ref14 x 6
M01_ref15 x 6
M01_ref16 x 6
M01_ref17 x 6
M01_ref18 x 6
M01_ref19 x 6
M01_ref20 x 6
M01_ref21 x 6
M01_ref22 x 6
M01_ref23 x 6
M01_ref24 x 6
M01_ref25 x 6
M01_ref26 x 6
M01_ref27 x 6
M01_ref28 x 6
M01_ref29 x 6
M01_ref30 x 6
M01_ref31 x 6
M01_ref32 x 6
M01_ref33 x 6
M01_ref34 x 6
P01_base
P02_yaw_carrier
P03_shoulder_XL430
P04_extension_XL430
P05_wrist_XL430
P06_fixed_gripper_XL430
P07_moving_gripper_XL430

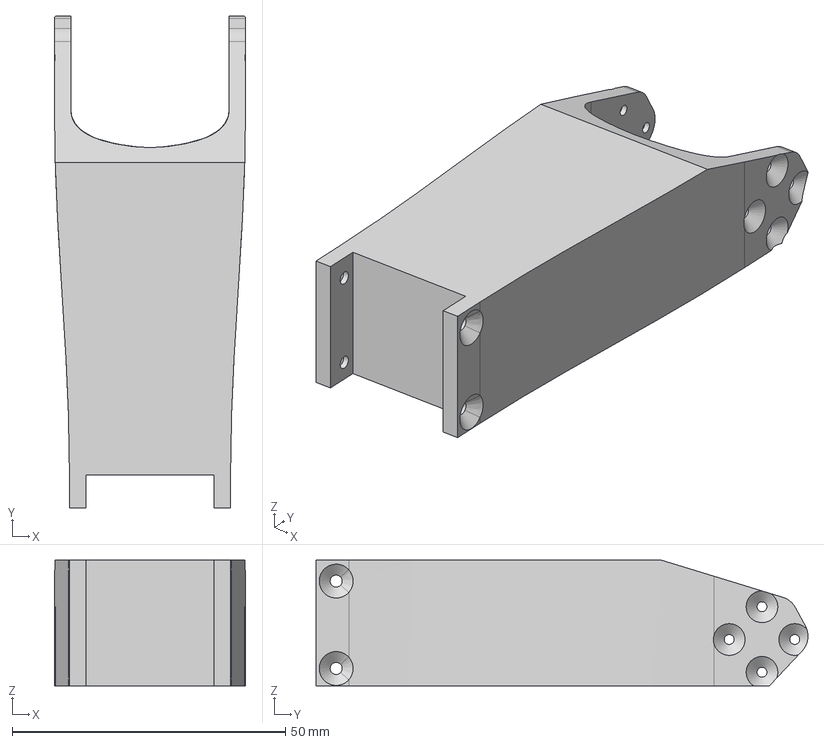
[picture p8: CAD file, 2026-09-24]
references/lateral-agent-20260922/low_cost_robot-gripper-camera-lateral-20260922/hardware/follower/step/elbow_to_wrist_extension.step
35.0 x 90.1 x 23.0 mm

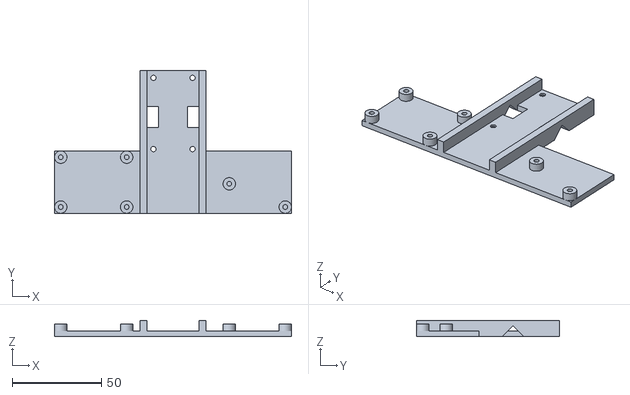
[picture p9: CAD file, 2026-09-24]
references/lateral-agent-20260922/low_cost_robot-gripper-camera-lateral-20260922/hardware/follower/stl/base.stl
133.0 x 80.0 x 9.00

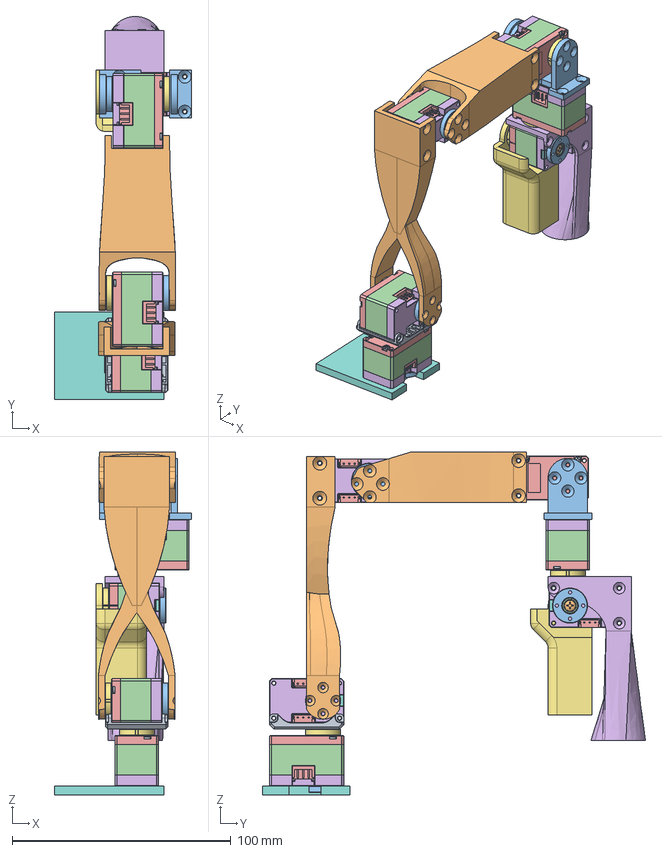
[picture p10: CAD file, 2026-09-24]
references/lateral-agent-20260922/low_cost_robot-gripper-camera-lateral-20260922/hardware/leader/step/leader_arm.step
62.7 x 175.0 x 156.5 mm
Servo Connector redesign
shoulder_rotation
DC15_A01_CASE_M_DUMMY x 6
DC15_A01_CASE_F_DUMMY x 6
DC15_A01_CASE_B_DUMMY x 6
DC15_A01_HORN_DUMMY x 6
DC15_A01_LED_CAP2_DUMMY x 6
PHS_1_7X20_5_DC10 x 24
BTS2_M2_6X8 x 12
DC15_A01_HORN_IDLE2_DUMMY x 6
DC15_A01_IDLE_CAP_DUMMY x 6
B3B-EH x 12
handle
trigger
base
fpx330-s101
connector

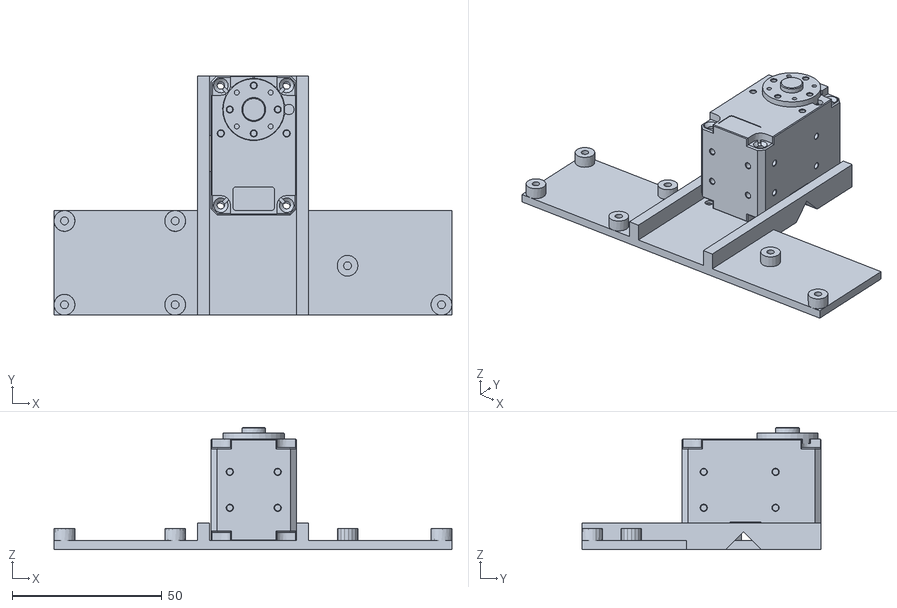
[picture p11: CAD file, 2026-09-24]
references/lateral-agent-20260922/low_cost_robot-gripper-camera-lateral-20260922/simulation/low_cost_robot/assets/base_link.stl
133.0 x 80.0 x 40.9

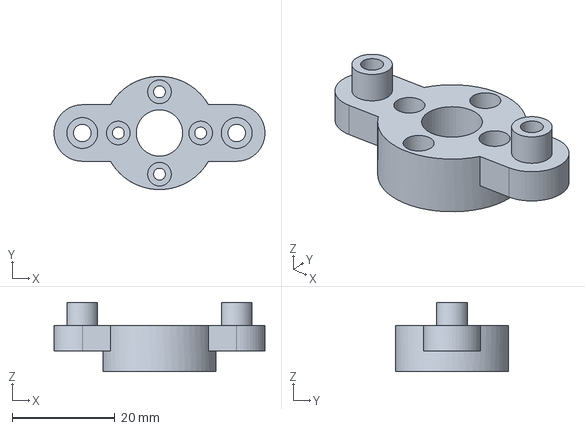
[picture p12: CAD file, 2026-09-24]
references/pg2-r5/PG2_XL430/CAD/parts/04_crank.step
41.0 x 22.0 x 13.5 mm

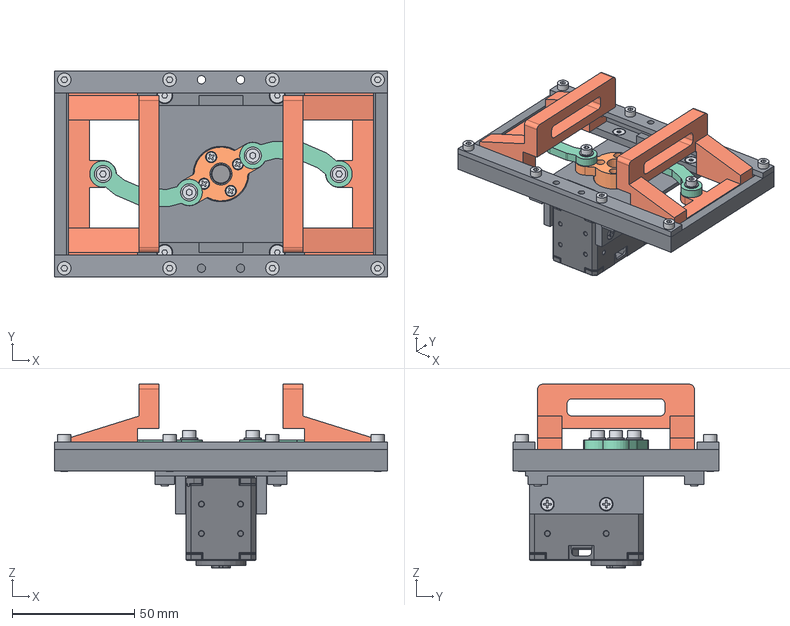
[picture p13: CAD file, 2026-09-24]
references/pg2-r5/PG2_XL430/CAD/PG2_open.step
136.0 x 84.0 x 75.0 mm
frame
retainer_top
retainer_bottom
motor_mount
XL430_W250
rail_bolt_-64_-38.5
rail_nut_-64_-38.5
rail_bolt_-21_-38.5
rail_nut_-21_-38.5
rail_bolt_21_-38.5
rail_nut_21_-38.5
rail_bolt_64_-38.5
rail_nut_64_-38.5
rail_bolt_-64_38.5
rail_nut_-64_38.5
rail_bolt_-21_38.5
rail_nut_-21_38.5
rail_bolt_21_38.5
rail_nut_21_38.5
rail_bolt_64_38.5
rail_nut_64_38.5
mount_bolt_-23_-32
mount_nut_-23_-32
mount_bolt_-23_32
mount_nut_-23_32
mount_bolt_23_-32
mount_nut_23_-32
mount_bolt_23_32
mount_nut_23_32
servo_tap_-1_-28
servo_tap_-1_-4
servo_tap_1_-28
servo_tap_1_-4
horn
crank
horn_M2_8_0
horn_M2_-8_0
horn_M2_0_8
horn_M2_0_-8
jaw_1
link_1
crank_pivot_bolt_1
crank_pivot_nut_1
crank_pivot_washer_1
jaw_pivot_bolt_1
jaw_pivot_nut_1
jaw_pivot_washer_1
jaw_-1
link_-1
crank_pivot_bolt_-1
crank_pivot_nut_-1
crank_pivot_washer_-1
jaw_pivot_bolt_-1
jaw_pivot_nut_-1
jaw_pivot_washer_-1

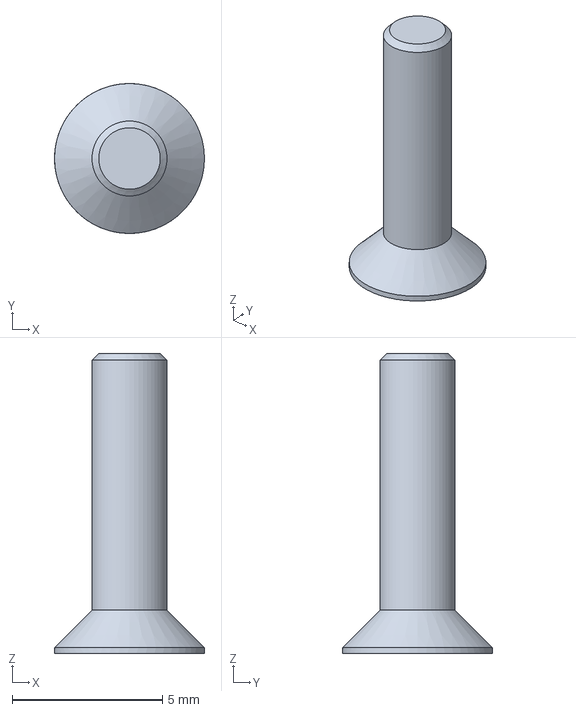
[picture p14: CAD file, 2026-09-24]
references/pg2-r5/PG2_XL430/reference/026__0_1_1_18_.step
5.00 x 5.00 x 10.0 mm

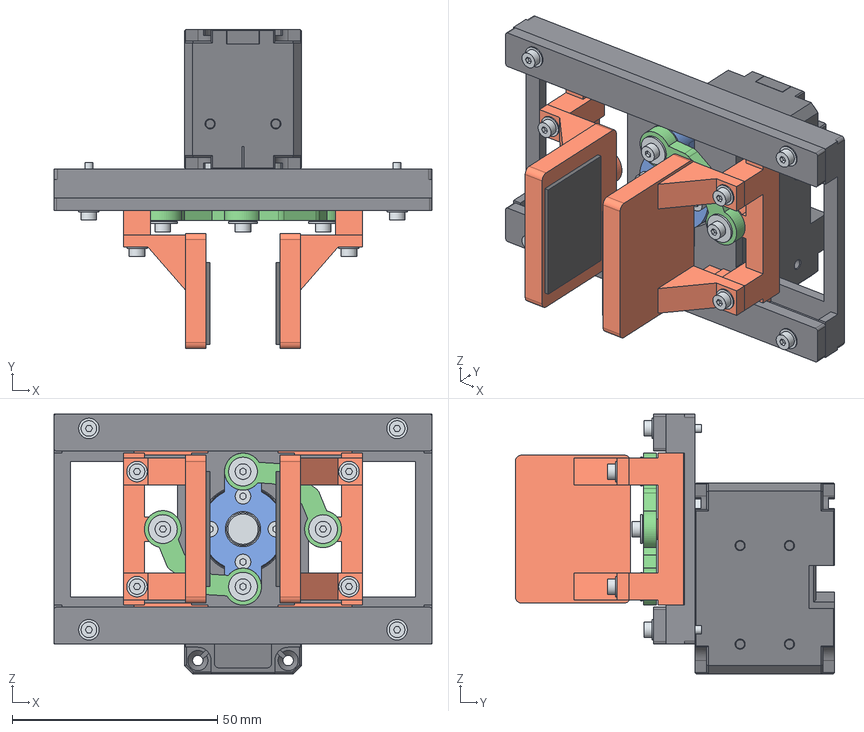
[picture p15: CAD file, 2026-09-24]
references/pg3-c9/PG3_C92_J28/CAD/C92_J28_mid.step
92.0 x 77.7 x 63.2 mm
frame
cap_U
cap_D
crank
horn_spacer
carriage_R
finger_R
pad_R
link_R
carriage_L
finger_L
pad_L
link_L
XL430_fixed
XL430_horn
pivot_drive_R_washer
pivot_drive_R_bolt
pivot_drive_R_nut
pivot_drive_L_washer
pivot_drive_L_bolt
pivot_drive_L_nut
pivot_carriage_R_washer
pivot_carriage_R_bolt
pivot_carriage_R_nut
pivot_carriage_L_washer
pivot_carriage_L_bolt
pivot_carriage_L_nut
cap_-37.5_-24.5_washer
cap_-37.5_-24.5_bolt
cap_-37.5_-24.5_nut
cap_-37.5_24.5_washer
cap_-37.5_24.5_bolt
cap_-37.5_24.5_nut
cap_37.5_-24.5_washer
cap_37.5_-24.5_bolt
cap_37.5_-24.5_nut
cap_37.5_24.5_washer
cap_37.5_24.5_bolt
cap_37.5_24.5_nut
finger_R_-14_washer
finger_R_-14_bolt
finger_R_-14_nut
finger_R_14_washer
finger_R_14_bolt
finger_R_14_nut
finger_L_-14_washer
finger_L_-14_bolt
finger_L_-14_nut
finger_L_14_washer
finger_L_14_bolt
finger_L_14_nut
horn_bolt_0
horn_bolt_1
horn_bolt_2
horn_bolt_3
case_tapper_-11
case_tapper_11

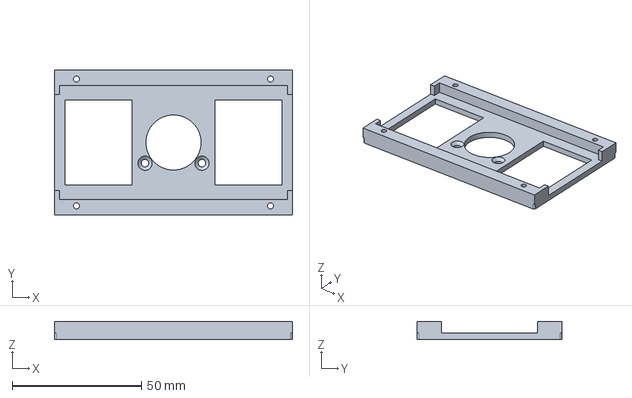
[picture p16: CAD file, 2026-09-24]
references/pg3-c9/PG3_C92_J28/CAD/parts/01_frame.step
92.0 x 56.0 x 7.10 mm

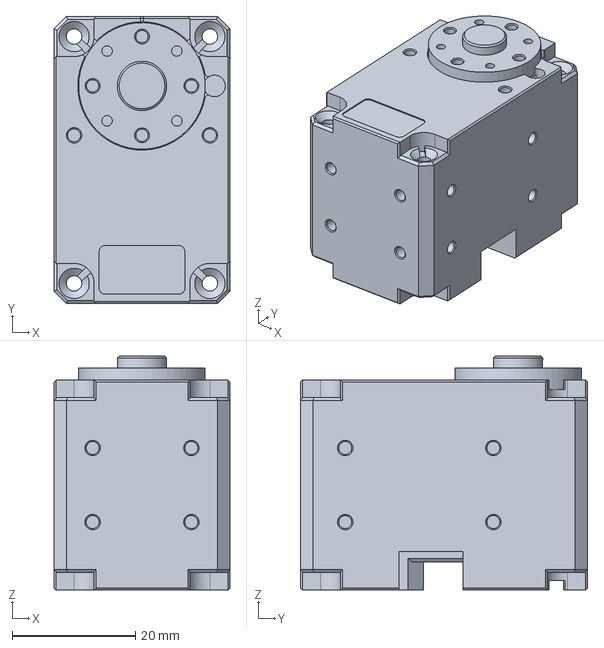
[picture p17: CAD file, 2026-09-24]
references/pg3-c9/PG3_C92_J28/reference/C7/reference/XL430_from_supplied_arm.step
28.5 x 46.5 x 37.9 mm

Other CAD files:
references/pg3-c9/PG3_C92_J28/STL/changed_parts/05_finger_R.stl
references/pg3-c9/PG3_C92_J28/STL/unchanged_C7/08_link.stl
references/prior-checkpoint/j4-datum-20260922/CAD/arm_all_XL430_static_UNACCEPTED.step
references/prior-checkpoint/j4-datum-20260922/CAD/parts/gripper_moving_unchanged.step
references/arm-baseline/step/arm.step
references/arm-baseline/step/gripper_moving_part.step
references/arm-baseline/step/gripper_static_part.step
references/arm-baseline/step/shoulder_rotation.step
references/arm-baseline/step/shoulder_to_elbow.step
references/arm-r3/P05_wrist_XL430.step
references/lateral-agent-20260922/low_cost_robot-gripper-camera-lateral-20260922/hardware/follower/follower_arm.f3z
references/lateral-agent-20260922/low_cost_robot-gripper-camera-lateral-20260922/hardware/follower/step/arm.step
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

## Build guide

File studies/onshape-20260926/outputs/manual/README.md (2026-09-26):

# スクリーンショット付き作業マニュアル

- `MANUAL.html`：ブラウザで開く。画像をクリックで拡大。画像を内包しているため、このファイル単体で読める。
- `MANUAL.pdf`：A4・25ページ。配布・印刷用。
- `MANUAL.md`：編集用原稿。画像は同じフォルダの `images/` を参照する。
- `images/`：本文20図、追加証拠2枚。原画像は変更せず、必要な画面範囲をブラウザで撮影した。
- `verification.json`：レイアウト・画像・変換手順の検証記録。

再現用スクリプトは上位フォルダの `reproduce/`、URDFは `robot/` と `rebuild/robot/`。全てまとめた配布物は上位の `onshape-robot-bundle.zip`。

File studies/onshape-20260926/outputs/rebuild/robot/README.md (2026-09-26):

Kinematic Onshape export. See the top-level README.md and VALIDATION_GUIDE.md in the full bundle.
Use robot.urdf with assets/. robot.onshape-raw.urdf is the preserved raw exporter result.
Run pg3_states.py to obtain nonlinear closed-loop joint states; run validate_robot.py with numpy/trimesh.
Mass, inertia, hardware home and effort/velocity are unmeasured. No dynamics/control acceptance.

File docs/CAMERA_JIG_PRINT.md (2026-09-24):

# Camera jig: single-job trial print

Date: 2026-09-22. The user requested all newly made jig parts in one print job
and confirmed the previous Ender-3 Pro / 0.4 mm nozzle / PLA setup.
This authorizes prototype printing, not mechanical or operational acceptance.

## Delivered File

- SD volume: `sd_card_3d`, removable Transcend card, `/dev/sdd1` at time of copy.
- SD root filename: **`camjig.gcode`**.
- Source: `outputs/print-camera-20260922-final/plate_1.gcode`.
- SHA-256: `ff535ae69a3583126634f063f86afe6b45f5cddeb75d59d1695b367deccf5c17`.
- Existing SD files were preserved. The copy was flushed with `sync -f`,
  reopened and hashed; source and destination hashes matched.
- `udisksctl unmount -b /dev/sdd1` succeeded. The card can be removed.
- Printing was NOT started remotely. No serial ports or motors were accessed.

Only the `final` run above is the SD deliverable. The `r1` and `r2` directories
are diagnostic runs and were not copied to the card.

## Contents And Settings

| Part | Quantity | Print orientation |
|---|---:|---|
| saddle | 1 | Upright on clamp bottom, with generated supports |
| front_jaw | 1 | Broad face flat, rotation +90 degrees about X |
| camera_spacer | 1 | Original local XY plane flat |

All three parts print layer by layer on **one plate**, not sequentially by
object. No motors, arm links, camera electronics or fasteners are printed.
The source CAD is unchanged; print preparation applies only rigid transforms.

| Setting | Value |
|---|---|
| Printer / nozzle | Creality Ender-3 Pro / 0.4 mm |
| Slicer | OrcaSlicer 2.4.2, headless CLI |
| Material | Generic PLA |
| Hotend / bed | 220 C / 60 C; initial hotend warmup 150 C |
| Model / initial layer height | 0.20 / 0.20 mm |
| Walls / infill | 4 / 35% gyroid |
| Supports | Normal automatic, including supports on model where needed |
| Support top / bottom gap | 0.20 / 0.20 mm |
| Support interface / XY gap | 3 layers / 0.35 mm |
| Brim | 5 mm, separation gap 0.1 mm |
| First-layer speed | 20 mm/s |
| Estimate | 2 h 42 min 37 s; 24.09 g PLA |

Support layers can occur between model layers. The reported 428 layer changes
are not a claim of 428 model layers at 0.20 mm. Actual extrusion height is
63.8 mm; the end-of-job parking move reaches Z150 mm.

## Verification And Warning Decision

- `uv run pytest -q`: **17 passed**, including rejected disconnected/open meshes,
  out-of-bounds moves, wrong temperatures, sequential printing, missing heater
  shutdown, pause commands and unreviewed slicer warnings.
- `uv run ruff check camera_jig/prepare_print.py tests/test_prepare_print.py
  scripts/orca_presets.py scripts/preview_gcode.py`: passed.
- Input STEP hashes match the source CAD validation record. Each print STL is
  closed, consistently wound, one connected component, with positive volume and
  volume deviation from B-rep below 0.5%. No implicit slicer mesh repairs.
- One plate, exactly three allowed objects, all present in emitted G-code.
  Motion is within the printer envelope and final heater shutdown is present.
- Actual extrusion paths were rendered and visually inspected in
  `outputs/print-camera-20260922-final/toolpath-preview.png`: separated objects,
  bed-contained layout, saddle supports and retained frame openings visible.
- G-code validation: `outputs/print-camera-20260922-final/gcode_validation.json`.
  Inputs, transforms, profile snapshots and slicer binary hash are retained
  beside it in `preparation.json`, `machine.json`, `process.json`, `filament.json`,
  `job.3mf`, `result.json` and `slicer.log`.

There is **one reviewed warning**, not zero warnings:
`bed_temperature_too_high_than_filament` / `1000C001` in the 3MF archive.
Orca 2.4.2 compares maximum bed temperature with configured vitrification
temperature using `>=`; this PLA preset sets both to 60 C.
See the [version-pinned Orca implementation](https://github.com/OrcaSlicer/OrcaSlicer/blob/v2.4.2/src/libslic3r/GCode/GCodeProcessor.cpp#L5551-L5577).

Decision: retain the standard 60 C bed used in the previous test print.
Do not falsify the material temperature to suppress the warning. The validator
defaults to rejection and permits this specific reviewed condition only with
PLA, a 60 C hot-plate preset and matching actual G-code. Tests confirm that a
65 C bed or additional warning remains rejected. This software warning review
does not establish PLA strength, creep life or real adhesion.

## Printing And Assembly Checks Still Required

Select `camjig.gcode` on the printer and observe first-layer adhesion. After
cooling, remove supports and brim, clear the holes and inspect the thin frame
and support-contact surfaces before trial fitting. Do not force a poor fit.

Fit camera and spacer to the saddle on the bench before attaching the clamp:
installed-camera tool access is known to fail in the checked arm pose.
Follow [the assembly sequence and unresolved checks](CAMERA_JIG.md).
Fasteners and tools are not yet selected. Retention, printed fit, PLA creep,
camera field of view, wiring and full joint-range clearance remain unverified.
The `fabrication_approved: false` field in the CAD evidence remains unchanged;
it denotes missing engineering acceptance, not withdrawal of this explicitly
requested trial-print deliverable.

## Reproduction

From the repository root, use a new output directory each time:

```bash
rtk proxy uv run python -m camera_jig.prepare_print --out outputs/print-camera-next
rtk proxy uv run python scripts/preview_gcode.py \
  outputs/print-camera-next/plate_1.gcode \
  outputs/print-camera-next/toolpath-preview.png
rtk proxy uv run pytest -q
```

Inspect the new validation, 3MF warnings and preview before any later SD copy.
The system presets are local inputs and may change; this run's flattened
snapshots and slicer hash are the evidence for the delivered job.

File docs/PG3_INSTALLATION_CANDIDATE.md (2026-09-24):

# PG3 C9 + P05 camera installation candidate

2026-09-23. Repository: project root (`3d-printed-dynamixel-gripper`).
Execution record: `temp/workdoc_Sep23-2026_pg3_installable.md`.
**Installation DoD remains open. This is a locally modified assembly, not merely a relocated camera renderer.**

For the concise acceptance matrix and missing inputs, see
[Installation readiness](INSTALLATION_READINESS.md). Diagnostic PASS is not release approval.

## 2026-09-24 Requirements Change

The user no longer requires roll, superseding the earlier +/-30 degree request.
ID5-only jaw actuation with no additional motor is now user-confirmed.
See [current design](PG3_ID5_ONLY_DESIGN.md). The physical CAD mapping remains
unobserved. The r5 layout below is
historical evidence, not a completed implementation of this new architecture.
Camera purchase is pending; retain the reference 28x28 mm four-hole interface.
The object is a cube, with size/mass unspecified. P05 local cable-relief candidate
design and a reprint proposal are authorized, preserving source STEP, existing
bores, fastening/contact faces and support function. No printing or power approval.
OEM M2.6x5 tapping screws are absent or possession is unknown.
The permission resolves the former P05 authorization gate, not geometry, strength
or real harness fit. Do not cut the old M05 route into a new layout blindly.

## Current Acceptance Boundary

The active entrypoint is `specs/project.yaml` -> `specs/gripper_variants.yaml`
-> `installation_candidate`. Top-level PG3 catalog fields describe the original
intake diagnostic; they are retained as history, not the current modified assembly.
Current frozen geometry is r5; r4/r3 and their supplemental audits remain history. No partial audit
rewrites the original whole-assembly collision report into a PASS.

The preferred **candidate for further assembly validation** is now bench fastening
of the four pivots, followed by held linkage/spacer insertion and horn fastening.
This can avoid the in-situ temporary-screw exchange, but handling, fastener loading
and the installation gates below are still unresolved. See "Bench-Preassembled
Linkage Alternative"; this is not a released assembly instruction.

| Remaining gate | Next evidence required | Dependency |
|---|---|---|
| Saved-assembly contact classification | Resolve each pair with controlled Booleans or complete-material bounds; distinguish nominal seats from positive clearance and retain unclassified pairs | Agent CAD work; not waiting on camera purchase |
| Motion and assembly paths | Fixed-mid G1-G7 nominal body paths are covered below; complete nut/fastener loading and remaining whole-arm motion checks | Agent CAD work; required physical arm range remains unknown |
| M05 cable egress | An accepted route with actual cable envelope/bend limits, including a separate second cable exit | Cable specification; P05 local-relief permission if that solution is adopted |
| Camera observation and support | Required grasp ROI across required roll range; actual optical model, mass and PLA support assessment | Camera/operating requirements; a reference proxy is not acceptance |
| Fasteners and tools | Exact screw head/thread/lead, full-form engagement, bottom clearance and actual tool access | Hardware identification; nominal geometry alone is insufficient |
| Printed installation | Version-matched fabrication package, fit and nonpowered assembly observations | Prior gates and user physical trial; not performed by CAD scripts |

The unchanged P05 and unresolved cable routing prevent installation release.
The first two rows are independently actionable; external unknowns do not justify
stopping all CAD work. Do not treat unproven strength, friction or preload as
results of the kinematic MuJoCo demonstration.

Latest full repository regression at section42: **392 passed**, 8 existing
CadQuery deprecation warnings, 712.85 seconds. This includes the crank representation
and installed-assembly mesh-source regression tests. The381-test result belongs
to section40; 356 to section36; 310 to G7. None is physical
installation evidence. A dedicated headless Chili3D import of the frozen r5 mid
STEP matches all 309 named occurrences in DOM; whole-arm and terminal screenshots
and input/artifact hashes are in `outputs/pg3-r5-browser-r1/`. Console: 0 errors,
11 warnings. This checks viewer identity, not browser-kernel geometric equivalence.

### r5 Integration Checkpoint

`outputs/pg3-installable-candidate-r5/` integrates the same-dimension crank
representation repair from section41. Its replacement map exports a native
manufacturing STEP/STL and supplies the installed occurrence. Controlled native
material comparison against the supplied07_crank gives zero directional residuals
and2.046e-12 mm3 common-volume error, with passing operand identity checks.

The simulation exporter previously meshed PG3 parts from cached `model.neutral`
while using the installation factory only for the other parts. Consequently the
r4 simulation did not contain the locally relieved frame. Section42 corrects
that selection: every PG3 mesh comes from the installed mid assembly, inverse-
transformed into the mechanism frame. Missing/extra PG3 occurrences are rejected.
Replacement-geometry and inventory regression tests failed before this change.
The saved-STEP reconstruction in section41 already avoided the stale-source path.
Historical camera diagnostics retain their original scene hashes and are not
automatically promoted to r5 evidence.

All three r5 saved poses retain309 occurrences and the same24795 pair inventory:
24741 PASS,44 ERROR,10 UNKNOWN. Exactly six statuses per pose change from ERROR
to PASS: crank against two drive nuts and four horn screws. All other statuses
are unchanged. Raw errors are retained; this is not installation approval.
All413 recorded output hashes and19 captured source files match their files.
The seven changed-part meshes are single-component and watertight.

The refreshed6-DOF/two-loop simulation gives closure error6.641e-12 mm and pad-gap
error4.168e-12 mm. Its nine camera samples pass framing/nonzero-visibility only;
partial finger/pad occlusion remains visible. Gravity, force, real optics, actual
fasteners and PLA fit are not validated. X/Y/Z terminal views and the closed/+30
roll reference image were inspected. No fabrication or powered-operation flag
has been enabled. Camera ROI, cable egress and the remaining acceptance gates
above are still open.

### r5 Saved Interfaces And Candidate BOM

Section43 reruns the following against the saved r5 STEP files, not inherited
r4 status. Evidence directory: `outputs/pg3-installable-candidate-r5-audit/`.

| Report | Verified scope | Remaining boundary |
|---|---|---|
| `components_r1.json` | All54 raw unresolved pairs in each of3 poses;5 camera pairs clear by all-solid decomposition |49 remain UNKNOWN under this method; non-solid material was not discarded |
| `mating_regions_{open,mid,closed}_r1.json` | Support/M05 and spacer/horn covers clear;8 support screws stay within receiver regions |Actual threads, full-form engagement, preload and strength |
| `drive_receivers_{open,mid,closed}_r1.json` |6 PG3 mounting screws align/seat; horn insertion2.5 mm, bottom margin1.0; case insertion2.65, margin1.35 |Actual OEM head/lead/recess/tool matching |
| `bench_cluster_r1.json` |18 moved parts versus240 stationary parts,4320 translation pairs; bound2.003730515e-9 mm3;144 bench and2096 final horn tool pairs PASS |Handling an articulated cluster/spacer, actual tools, loading, tolerances, wires and other arm poses |
| `bom_r2.json` |95 terminal CAD occurrences covered once,94 physical items; input STEP SHA pinned |Not an upstream-arm BOM or purchasing/fabrication approval |

These disjoint supplements cover seven raw pairs with nonpenetration evidence
and fourteen with conditional receiver geometry. At section43,33 still lacked a
new r5 classification. Section44 below adds the fixed/horn display-partition bound;
32 supplier-internal reference pairs remain unaccepted. The raw44 ERROR/10 UNKNOWN
report is unchanged, and a nominal bound is not physical motor approval.

The previous `BOM_DRAFT.md` still mixed the rack concept with camera items and
omitted the PG3 hardware inventory. It now describes this candidate only, with
`specs/pg3_candidate_bom.yaml` as its machine-readable quantity source. The
checker rejects missing/extra terminal occurrences, duplicate selectors, wrong
quantities, altered scope, and a STEP from another revision. Only the explicitly
named fixed/horn motor display partition maps two occurrences to one physical
motor. Camera and pivot screws with the same nominal M2 length remain separate
because their modeled head heights differ. Cable and supplier hardware unknowns
remain explicit; the94-item count does not make the installation BOM complete.

```bash
rtk proxy uv run python -m scripts.check_pg3_bom \
  outputs/pg3-installable-candidate-r5 --out outputs/UNUSED-pg3-bom.json
rtk proxy uv run python -m scripts.review_pg3_bench_cluster \
  outputs/pg3-installable-candidate-r5 --out outputs/UNUSED-bench-cluster.json
```

The inventory command exits0 only for quantity reconciliation; the bench command
exits2 to retain the installation boundary. No CAD geometry was changed in section43.

### r5 Motion And Supplier Representation

Section44 adds the following r5-audit reports without geometry or tolerance changes:

- `motor_partition_r1.json`: all266 fixed-side faces accounted for in each saved
  pose; horn/contact-volume upper bound6.665831370284378e-5 mm3 against the existing
  1e-4 criterion. Rearward0.2 mm and added-material controls are rejected.
  This is a nominal display partition under declared rotation, not a physical bearing design.
- `continuous_opening_r1.json`: fixed-upstream opening25..135 degrees gives11073
  PROVEN_CLEAR,11 UNPROVEN and187 RIGID_RELATION_UNCHANGED. The36315 stationary
  pairs are not reassessed by this motion checker; all47586 pair identities remain accounted for.
- `pivot_motion_r1.json` and `horn_sweep_r1.json`: whole-host/link proofs resolve4
  pairs and complete supplier-spacer/rotor envelopes resolve2. Combined11079 clear,
  5 unproven and187 unchanged rigid relationships. The input/base-proof hashes are linked.
- `washer_contacts_r1.json`: all3 saved poses and both drive washers satisfy the
  nominal spin-invariant contact proof, with6 rejected displacement controls per
  pose. These4 contact pairs and the display partition account for the5 remaining
  non-rigid pairs. They are not relabeled positive clearance. Axial float, deformation,
  actual preload, all-arm motion, cables and physical motor internals remain outside this proof.

`supplier_inventory_r1.json` records why the remaining32 internal pairs cannot
be classified just by source leaf number. The official and R3 STEP each have35
leaves, but22 indices exchange positions, notably solids and surface details.
Under the single reviewed Ry90/T(-0.2,234.9,164.6) frame, a unique bounds/material-kind
correspondence has maximum bbox error4.3268e-7 mm. A naive ordinal pairing instead
has maximum bbox error24.6424 mm. The35 R3 leaves contain23 one-solid entries,
11 surface-only entries and one two-solid body. The official body's345 faces
versus R3's292 are recorded rather than silently healed.

All34 retained M06 occurrences match the original R3 finite signatures. Each
unresolved internal pair links that signature, the R3 manifest row and the
official envelope correspondence candidate. These are source-tracing facts only:
matching outer bounds can conceal different material, as a negative fixture
demonstrates. Neither those32 raw pairs nor actual motor construction is approved.

```bash
rtk proxy uv run python -m scripts.review_pg3_supplier_inventory \
  outputs/pg3-installable-candidate-r5 --out outputs/UNUSED-supplier-inventory.json
```

The checker is read-only, rejects ambiguous/missing/mismatched material-kind
inventories, records source hashes, and deliberately exits2. It does not infer
physical IDs from M-labels or authorize fabrication.

### Removable Bench Support Candidate

Section37 adds `gripper_design/pg3_bench_support.py` and the corresponding
`scripts.review_pg3_bench_support` checker. Saved artifacts are under
`outputs/pg3-bench-support-r1/`; this does not replace or modify frozen r4.
The48x60x3 mm base has four annular posts, outer radius1.9 / tip bore radius1.2 mm,
at the saved nut axes. Drive posts are1.2 mm high; carriage posts3.55 mm high.
Print +Z maps to source-world +X through a right-handed rigid transformation.

Reimported STEP matches the generated solid; STL is watertight, consistently
wound and one component. Jig against all17 linkage parts passes, as do four
opposed nut seats (6.81725605829 mm2 each) and144 tool/body combinations.
Lifting the fixed-mid linkage60 mm off the jig has aggregate continuous
intersection-volume upper bound0 mm3. This is contact-compatible nominal
geometry, not a positive-clearance or physical assembly certificate.

The horn spacer is separate and absent on this bench jig, not silently removed
from the eventual arm installation. The posts support nut backs but do not locate
loose nuts laterally. Practical loading/hand access, actual threads/torque,
0.7 mm wall printability/strength and height tolerances remain unverified.
No G-code, fabrication release or arm-installation approval is issued.
The checker exits2 and retains both approval flags asfalse even on nominal PASS.
The new eight tests plus six existing bench-cluster tests pass (14total,
65.31 seconds); the whole suite was not rerun after this isolated addition.
The frozen409-file checkpoint and81-file donor hashes remain unchanged.

Section38 separately checks individual nominal loading paths with
`scripts.review_pg3_bench_loading`: four nuts first, then crank, the two carriages,
the two links, followed by each pivot washer and bolt. Each of17 stages retains
every previously installed item, covering153 mover/obstacle pairs. All paths
start60 mm along source +X from the saved-mid orientation.
The initial generic report (`bench_loading_r1.json`) leaves seven stages unproven.
The supplemental report (`bench_loading_r2.json`, both in the r4-audit directory)
keeps those raw results and bounds four host/nut pairs by inverse relative nut
motion and eight bolt/receiver pairs by the existing whole-material axial bound.
All stage bounds meet1e-4 mm3; the largest is3.518587843e-6 mm3, not a measured
penetration. Two world-frame crank/nut enclosure checks remainERROR, with the
explicit common rigid-frame checks supplying the supplemental evidence instead.
No partner is removed and no tolerance or source shape is changed.
These paths do not establish loose-nut stability, actual threaded engagement or
tightening. Holding an articulated linkage and the separate spacer during the
subsequent arm insertion remains a physical task, not a rigid-body assumption.
The five focused files (bench loading/support/cluster, nut loading and screw
exchange) pass47 tests in151.04 seconds. Full-suite status remains the older
section36 checkpoint; section38 records both raw/supplemental source archives.

To regenerate the candidate headlessly, choose a **new, unused** output path:

```bash
rtk proxy uv run python -m scripts.review_pg3_installation --out outputs/pg3-install-next
```

This command generates diagnostic evidence, not installation approval. Read the
report statuses and supplemental checks; success of the process is not a release gate.

### Boolean Input Diagnostics

`r3-audit/boolean_arguments_r1.json` narrows, but does not fix, the crank failure.
`scripts/probe_pg3_saved_boolean.py` compares neutral/in-memory/saved crank solids
and explicitly enables four OCP argument checks (self-interference, small edges,
face rebuilding checks and curve-on-surface checks). All crank inputs have no
reported faults and classify the infinite point as OUT. Nevertheless, the saved
world solids return zero common volume with their independent copies, instead of
approximately1240.16165 mm3. The common rigid re-expression restores that identity
for saved mid/closed, but not open. In-memory world geometry also fails, so this
is not isolated to serialization. Argument validity is not Boolean reliability.

A4 mm box supplies a valid control; two overlapping4 mm solids produce explicit
self-interference faults despite topological validity. Neither control permits
accepting the failed crank operations. No healing, tolerance change or geometry
replacement was applied. The script deliberately exits2 and records
`installation_approved=false`; all unresolved assembly contacts remain unresolved.

## Continuous Opening Check Method

`scripts/review_pg3_motion_clearance.py` checks the25..135 degree PG3 relative
mechanism interval while the upstream arm/wrist stays fixed. It uses saved checkpoint
mid geometry and the existing analytic group transforms, not a new approximate
mechanism or a three-frame collision sample.

The checker first tests separation along an analytically invariant axis. Every
branch of the reviewed `pg3.group_transform` consists solely of construction-Rz
rotation and XY translation, so every material point retains its construction Z.
The fixed `to_arm` Ry90 transform makes world X equal to construction Z minus0.2.
Consequently a positive gap between the complete shapes' world-X bounding intervals
is a lower bound on separation throughout the opening interval. Curved extrema
are included by B-rep bounding boxes; surface-only enclosures retain their existing
1e-5 mm expansion on both sides. Gaps must exceed the unchanged distance epsilon.
An overlapping projection is inconclusive, not a collision result.

This proof is tied to the reviewed whole `pg3.py` SHA256
`ac2da0e35e6665c5526ed03f02f1881c4edd8c69c1679c58add1810814b1b775`.
The checker verifies it before and after running. A source change fails closed
until the formulas, all motion groups and placement have been re-reviewed; do not
refresh the hash merely to make a failing check pass. A mutation adding axial
translation is a rejected test control. Sampled poses corroborate but do not prove
the invariant. Upstream arm/wrist motion is outside this fixed-arm certificate.
Pairs without this axis certificate proceed to the point-speed method below;
invalid inputs and unchanged rigid relationships retain their separate statuses.

For each moving part, the checker bounds the speed of every material point in
mm per mechanism radian. With crank radius14 and link length24, the slider bound
is `14 + 196/(2*sqrt(380))`; the moving pin bound is14; a link bound is
`14 + (14/sqrt(380))*rho`, where rho conservatively bounds all material relative
to its pin using the neutral AABB. A drive-group point's speed is bounded by its
maximum XY radius. For a pair, the sum of these speeds bounds how rapidly its
distance can decrease.

A midpoint distance exceeding that sum times the interval half-width plus
the existing numerical distance epsilon proves separation throughout the
interval. Otherwise the interval is subdivided. At most256 evaluations per
pair and a minimum0.5 degree interval are computation limits: reaching either
without proof is **UNPROVEN**, never a PASS. A zero distance can be intended
contact, penetration or a numerical issue; this checker does not classify it.

Non-solid occurrences are conservatively enclosed by their full AABB, never
discarded. Same-rigid-group pairs are recorded as unchanged relationships,
**not accepted contacts**. Fully stationary pairs remain covered by the separate
static report. A proven nominal gap is not a print-tolerance allowance, minimum
engineering clearance, strength assessment, cable clearance or full-arm motion
approval. This supplemental check cannot authorize installation on its own.

Run with a new output filename; the checkpoint is never regenerated or overwritten:

```bash
rtk proxy uv run python -m scripts.review_pg3_motion_clearance \
  outputs/pg3-installable-candidate-r4 \
  --out outputs/pg3-installable-candidate-r4-audit/continuous_opening_next.json
```

The historical r3 r1 run accounts for all47586 pairs:36315 fully stationary pairs and11271
moving-context pairs. Of the latter,11067 are PROVEN_CLEAR,187 have unchanged
rigid relationships, and17 remain UNPROVEN. The source snapshot
`r3-audit/continuous_opening_r1_checker.py` matches the report's checker hash;
the working script was subsequently line-formatted with identical AST.

**r3 print-fit concern:** both carriages have zero nominal clearance against
the frame's end lands at25 and31.875 degrees. Controlled Booleans find zero
intersection volume at those inspected poses, but boundary-distance witnesses
confirm contact, not a positive running gap. At38.75/90/135 degrees the distance
is0.3 mm. In construction coordinates the end lands start atY=+/-18.5, exactly
matching the carriage bridge's side faces. This is not grounds for increasing
motor force or approving printed sliding fit.

r4 implements the local frame relief recorded in workdoc step26, limited to four
end-land strips and retaining the original archive. The inspected saved-part
poses now have0.3 mm gaps and a continuous positive-separation test passes.
Physical print fit remains unverified; historical r3 retains zero clearance.
The completed r4 saved-assembly run is
`r4-audit/continuous_opening_r1.json`:11069 PROVEN_CLEAR,15 UNPROVEN and187
RIGID_RELATION_UNCHANGED, using19862 distance evaluations. Coverage is the same
11271 moving-context pairs plus36315 separately recorded stationary pairs.
Exactly two pair statuses changed from r3: each carriage against the frame.
Each required127 evaluations and64 certified intervals. Its minimum evaluated
distance lower bound is approximately0.3 mm, not an exact global-minimum result.
Assembly/checker/dependency hashes and pair coverage were independently checked.
The newer `r4-audit/continuous_opening_r2.json` adds the source-guarded axial proof:
11073 PROVEN_CLEAR,11 UNPROVEN and187 unchanged rigid relationships. All11271
moving-context pair identities are identical to r1. Exactly four statuses change:
each left/right link against its carriage and drive washer. Their nominal axial
separation lower bound is0.3 mm throughout the opening interval. The geometry and
distance epsilon are unchanged. Axis projection proves10069 pairs;1015 proceed
to the point-speed method, which performs5523 distance evaluations.

The remaining11 comprise six computation-limit cases and five zero-distance
contact candidates, not11 proven physical interferences. See workdoc section21.1.
The static50ERROR/10UNKNOWN and187 rigid relationships are not accepted by this
supplemental result. The r1 checker snapshot is retained alongside its report.
The donor's fixed/horn split is made by a cylindrical cut for rotation display
(`reference/C7/source/design.py:187`), not a supplier-validated contact model;
zero distance at that partition is not evidence of real bearing or press-fit quality.

### Whole-Host Pivot Clearance

`r4-audit/pivot_motion_r1.json` supplements exactly four previously unresolved
pairs: each link against its crank and carriage. It does not exclude those hosts
or accept their entire bodies merely because the pin fits its hole.

`axial_ray_cover` extends conservative projections of **every** host face back to
the host's axial minimum. Any material point in a finite closed solid has a
positive-axis ray that exits through one of those faces, so this covers interior
material too. Full curved extrema are bounded, with1e-7 mm outward padding.
Surface-only, invalid and inverted/unbounded solids are rejected. The actual
crank has41 faces and each carriage62; all206 face entries across the four pairs
were independently checked for complete coverage.

The actual link's two R2.7 through-bores are verified as empty cylinders spanning
its entire axial range, using controlled Booleans. A0.3 mm displaced cylinder
must detect penetration. The corresponding R2.5 shoulder trajectory is matched
to the link endpoint analytically: `P=s*(14*cos(t),14*sin(t))`,
`Q=s*(x(t),0)` and `|Q-P|=24`. The reviewed link transform maps both neutral
endpoints to these points. Rigid transforms do not amplify the measured neutral
centre offsets, whose sum is deducted from the radius gap. This proof uses the
same guarded kinematics source as the opening checker.

Only cover cylinders that fit wholly inside that proven void use this radial
certificate. All other covers require invariant-axis separation or the original
continuous Lipschitz test. Thus the opposite crank pin and raised finger-mount
material remain included. The pin-region nominal gap lower bound is approximately
0.1999999 mm; this is **not** a claim that the complete pair's minimum gap is0.2 mm.
The other covers have separately certified positive separation.

All four saved-r4 pairs passed. Four off-axis fixtures and one extra-material
fixture were rejected; a plugged bore and unbounded solid are also unit controls.
Combining these proofs with the unchanged base certificate yields11077 clear,
7 unproven and187 unchanged rigid relationships. Static contact errors, actual
printed fit, clamping load and strength are not accepted by this result.

```bash
rtk proxy uv run python -m scripts.review_pg3_pivot_motion \
  outputs/pg3-installable-candidate-r4 \
  --base-motion outputs/pg3-installable-candidate-r4-audit/continuous_opening_r2.json \
  --out outputs/UNUSED-pivot-motion.json
```

The command validates the base assembly/code/dependency hashes and full moving
pair inventory. It exits2 because installation remains unapproved, even when all
four pair certificates and their negative controls succeed. Do not overwrite
historical reports or promote unrelated inherited contacts to accepted status.

### Horn Rotation Envelope

`r4-audit/horn_sweep_r1.json` resolves the two complete supplier spacers
`ARM_M06_ref27/28` against the horn. Their source names are
`DC11_A01_SPACER_DUMMY:1/:2`; neither solid is excluded.
The horn's Boolean self-controls fail, so Boolean subtraction is not used to
prove its enclosure. All19 boundary faces are bounded analytically. Trimmed
circle bounds include in-range stationary extrema, not just vertices or samples.
Finite-solid boundary coverage then encloses the complete material.

The rotation-invariant cylinder has radius10.3 mm, transverse centre
`(Y,Z)=(234.9,164.6)` and X span15.2999999..20.7000001 mm. Maximum required
radius is10.250000100000253 mm. Its distance to each complete spacer is
approximately0.05147051 mm. The certificate covers the declared25..135 degree
opening interval with the upstream arm fixed, not arbitrary whole-arm motion.
Horn B-rep face/edge/vertex tolerances are1e-7 mm; the spacers' maximum stored
tolerance is1.45348e-6 mm. These are CAD tolerances, not manufacturing allowances.

Moving each spacer0.2 mm toward the axis produces approximately0.21274581 mm3
intersection with the conservative cylinder; both controlled negative fixtures
fail. This is **envelope** intersection volume, not actual horn penetration volume.
Together with the prior pivot proof, counts are now11079 PROVEN_CLEAR,
5 UNPROVEN and187 RIGID_RELATION_UNCHANGED. The remaining five are the motor's
visualization partition, two crank/washer and two bolt/washer contact candidates.
They require contact-specific evidence, not an invented positive clearance.
Static50 ERROR/10 UNKNOWN results and physical acceptance remain unchanged.

```bash
rtk proxy uv run python -m scripts.review_pg3_horn_sweep \
  outputs/pg3-installable-candidate-r4 \
  --motion outputs/pg3-installable-candidate-r4-audit/continuous_opening_r2.json \
  --pivots outputs/pg3-installable-candidate-r4-audit/pivot_motion_r1.json \
  --out outputs/UNUSED-horn-sweep.json
```

Exit2 is intentional. Input hashes, prior proof dependencies and the full pair
inventory are checked; an existing output is refused. The report retains
`installation_approved=false` and `physical_motor_interface_approved=false`.

### Drive Washer Seating And Retained Link Play

`r4-audit/washer_contacts_r3.json` classifies the two crank/washer and two
bolt/washer pairs as **NOMINAL_CONTACT**, not positive-clearance pairs.
Each saved open/mid/closed assembly passes both sides. All18 displaced fixtures
are rejected on geometric conditions; an evaluation ERROR cannot count as a
successful negative control. The earlier r1 report predates that distinction;
r2 adds it, and current r3 additionally rejects nonfinite Boolean volumes.

The complete washer is checked against an OD7/ID2.2/t0.5 annular solid with
controlled, bidirectional Booleans. Its verified round shape and centre
trajectory make its pin-only translation nominally equivalent to drive rotation
as a material set. This allows the contact relation to persist throughout the
guarded25..135 degree opening interval, with the upstream arm fixed. This is
numerical equivalence under declared tolerances, not exact set identity.
A missing sector, off-axis washer or extra bolt material must not inherit it.

The whole crank is at or behind X29.6; the washer occupies X29.6..30.1.
The complete bolt lies inside its measured shank/head cover. Its R1 shank fits
the washer R1.1 through-bore with nominal radial gap0.1 mm; its head begins at
X30.1. Both seating pairs have opposed outward normals. Common areas are
15.48019780 mm2 at the shoulder and7.53982237 mm2 at the screw head.
No failed crank Boolean is used as proof of whole-body nonpenetration.

The separate saved-r4 `pivot_stacks_{open,mid,closed}_r1.json` reports remeasure
all four link pivots in each pose: front/rear axial play0.3 mm each, radial
play0.2 mm, retaining overlap0.8 mm. These are nominal unloaded dimensions.
**The clamping path is screw head -> washer -> shoulder -> host/nut, not through
the moving link.** Actual shoulder compression, washer bending and printing
error can still consume this play. No tightening torque, strength or physical
free-motion approval follows from these CAD values.

The two0.3 mm gaps describe the modeled centred position; they are not two
independently guaranteed physical clearances. A3.2 mm link inside a3.8 mm
shoulder span has nominal **total axial play0.6 mm** and may move to either
seat. During a non-powered trial, measure the actual seat-to-retainer span and
link thickness, account for tightening deformation, then check free articulation
and retention throughout the required travel without forced spreading.
Touching a retaining face is not the same as clamping the link. Conversely,
positive unloaded play does not establish freedom after preload. The nominal
motion certificates do not include this axial float or manufacturing variation.

```bash
rtk proxy uv run python -m scripts.review_pg3_washer_contacts \
  outputs/pg3-installable-candidate-r4 --out outputs/UNUSED-washer-contacts.json
rtk proxy uv run python -m scripts.review_pg3_pivot_stacks \
  outputs/pg3-installable-candidate-r4/arm_camera_mid_CANDIDATE.step \
  --out outputs/UNUSED-pivot-stack.json
```

Both commands deliberately exit2. Old continuous-clearance counts remain
11079 clear /5 unproven /187 unchanged rigid relationships; the new report
provides nominal seating evidence for four of the five, not four new positive
gaps. The visualization-only fixed/horn partition and broader installation
requirements remain unresolved. No CAD geometry was changed in this review.

### Refreshed r4 Assembly Evidence

The saved r4 assembly was rechecked with the existing attachment, receiver,
component, tool-stage and insertion checkers. These are new r4 measurements,
not inherited r3 approvals. All files below are in
`outputs/pg3-installable-candidate-r4-audit/`.

| Evidence | Scope and current result | Not established |
|---|---|---|
| `components_r1.json` | All60 raw unresolved pairs, all three saved poses; five camera pairs clear by complete solid decomposition | Remaining55 pairs are UNKNOWN under this method; no surfaces were discarded |
| `attachments_mid_r1.json` | Saved P06 holes, seats, candidate depth and hardware/support geometry pass at mid | Actual parts, strength and full-arm motion |
| `mating_regions_{open,mid,closed}_r1.json` | P06/M05 and spacer/horn conservative-cover checks pass; eight new screws remain within bounded receiving regions | Actual threads, preload and thread-forming compatibility |
| `drive_receivers_{open,mid,closed}_r1.json` | Six PG3 mounting screws pass nominal receiver/seating checks per pose | Actual OEM head/tip/thread form or holding strength |
| `mechanism_lkey_stages_mid_r1.json` | 12932 tool/stage pairs pass under declared straight-tool/L-key envelopes and assembly order | Actual tools, bit fit, hand motion, cable-present service |
| `continuous_insertion_mid_r1.json` | Camera cluster4608 pairs and front jaw304 pairs pass the specified +Z60-to0 translation-volume check | Positive fitting clearance, alternative paths, moving arm, hands/cables |

Pair-by-pair reconciliation of each pose's original60 unresolved pairs yields:
**7 with supplemental nonpenetration evidence,14 with bounded receiver geometry
only,39 unresolved**. The39 consist of32 supplier-internal reference pairs,
the fixed/horn display partition, and six crank/screw-or-nut pairs. Origin in a
supplier assembly alone does not make those32 safe contacts. The14 receiving
regions likewise remain conditional until real fastener evidence is available.
The raw50 ERROR/10 UNKNOWN reports have not been changed, and no physical
installation approval follows from this reconciliation.

Re-run the current frozen input with new output paths. For receiver and mating
checks, repeat with `open`, `mid` and `closed`; stage/insertion checks below are
deliberately mid-only:

```bash
rtk proxy uv run python -m scripts.review_pg3_components outputs/pg3-installable-candidate-r4 --out outputs/UNUSED-components.json
rtk proxy uv run python -m scripts.verify_pg3_attachment_export outputs/pg3-installable-candidate-r4/arm_camera_mid_CANDIDATE.step --out outputs/UNUSED-attachment.json
rtk proxy uv run python -m scripts.review_pg3_mating_regions outputs/pg3-installable-candidate-r4/arm_camera_mid_CANDIDATE.step --out outputs/UNUSED-mating.json
rtk proxy uv run python -m scripts.review_pg3_drive_fasteners outputs/pg3-installable-candidate-r4/arm_camera_mid_CANDIDATE.step --out outputs/UNUSED-receivers.json
rtk proxy uv run python -m scripts.verify_pg3_service_stages outputs/pg3-installable-candidate-r4/arm_camera_mid_CANDIDATE.step --mechanism --horn-l-key --out outputs/UNUSED-tools.json
rtk proxy uv run python -m scripts.certify_pg3_insertion outputs/pg3-installable-candidate-r4/arm_camera_mid_CANDIDATE.step --out outputs/UNUSED-insertion.json
```

Several checkers exit2 by design while installation remains unapproved. Inspect
their structured results rather than interpreting the exit code alone as a
geometric failure or success. The focused checker regression rerun passed22
tests; no implementation changed, and the preceding full254-test run was not
rerun during this evidence refresh.
The ten reports are preserved in `installation_refresh_r1_evidence.tar.gz`.
All116 files in the existing `washer_contacts_r3_sources.tar.gz` still match
the current implementation byte-for-byte. Workdoc section25.4 records both
archive hashes. These bundles require the separate frozen r4 CAD input and
do not constitute a manufacturing release.

### Display Motor Partition Boundary

`motor_partition_r2.json` in the r4 audit directory checks all266 fixed-body
faces against the complete horn rotation envelope in each saved pose. Whole-
solid self-Booleans failed for this imported split, so they are not used as
zero-intersection evidence. One straddling face needs a controlled partition at
X15.3: area conservation, both residual directions, self-controls and side
bounds are checked. Its forward portion is11.055013945414 mm from the axis,
outside the declared horn envelope radius10.3 mm.

The possible boundary slab is counted, not discarded. Its volume upper bound
is6.665831370284378e-5 mm3, below the unchanged1e-4 mm3 threshold. The result is
**BOUNDED_PARTITION_CONTACT**, not exact zero or a positive fitting clearance.
It applies to the donor's displayed fixed/horn split under the declared axis;
it does not qualify the actual motor's bearing, preload or rotating interface.

All three poses reject both the backward-shifted horn and extra fixed material
within its conservative sweep. Rejection must beUNPROVEN, not a kernelERROR.
Nine new tests include known synthetic penetration, missing partition material,
extra solids, oversized contact slabs, failed evaluation, NaN and inverted
solids. The earlier r1 report has failed negative controls and is not accepted.

```bash
rtk proxy uv run python -m scripts.review_pg3_motor_partition \
  outputs/pg3-installable-candidate-r4 --out outputs/UNUSED-motor-partition.json
```

Exit2 retains the unapproved installation status. Report, checker, dependency
and assembly hashes are recorded in workdoc section26. The original raw60-pair
and continuous11079/5/187 ledgers remain unchanged. This supplements one display
partition question among the39 unresolved static pairs, not a physical release.

### Mechanism Body Insertion, Not Only Tool Access

`scripts/review_pg3_mechanism_insertion.py` checks saved r4 mid geometry against
the explicit G1/G2 assembly sequence. Tool withdrawal alone did not establish
that these bodies could reach their final positions. Both proposed body paths
retain orientation and translate from world+X60 mm to zero, before the camera
is installed. Nuts are assumed temporarily retained with their respective body;
loading and retaining those nuts is not established by this path check.

| Stage | Rigidly moved cluster | Already present | Full pair count | Total swept-intersection volume upper bound |
|---|---|---:|---:|---:|
| G1 | Frame and four cap nuts | 233 occurrences | 1165 | 2.2919888890343488e-10 mm3 |
| G2 | Crank, horn spacer and two drive nuts | 240 occurrences | 960 | 2.0037305148434825e-9 mm3 |

Two case screws follow G1 insertion; four horn screws follow G2 insertion.
No already installed obstacle is omitted. The report records full Cartesian
pair coverage and these later-installed screws separately. The acceptance budget
is1e-4 mm3 for the **sum across each stage**, not an allowance multiplied by
its number of pairs. This permits nominal contact; it is not a positive-clearance
or printed-fit certificate.

Independent proofs include full swept AABB overlap, conservative all-boundary
translation cover, and continuous occupied-distance bounds using the exact
translation speed60 mm per unit offset fraction. The spacer/horn proof encloses
all19 horn faces by a body and boss; all8 spacer faces exclude all spacer material
from the boss cylinder by a finite-solid exit-ray argument. Axial translation
preserves that radial exclusion. Its0.29999989999998 mm radial bound is local to
the boss, not the whole assembly's minimum clearance. Surface-only obstacles are
expanded AABB reservations; invalid or inverted material cannot take a bbox shortcut.
Earlier kernel errors and loose-cover results remain visible, not relabelled PASS.

```bash
rtk proxy uv run python -m scripts.review_pg3_mechanism_insertion \
  outputs/pg3-installable-candidate-r4 --out outputs/UNUSED-mechanism-insertion.json
```

Current report: `outputs/pg3-installable-candidate-r4-audit/mechanism_insertion_r5.json`.
Workdoc section28 records the source archive, hashes and34 focused passing tests.
The prior275-test full run was not repeated for this isolated new checker.
The command still exits2 because installation is not approved. G3 and later body
paths, nut loading/retention, hands, cables, actual fasteners, other arm poses and
physical assembly remain separate gates. Neither CAD geometry nor print release
was changed by this check.

### Sequential Slider And Link Body Insertion

The next six stages were checked against the same saved r4 mid STEP, using
`scripts/review_pg3_slider_link_insertion.py`. Each candidate body path retains
orientation and translates from world+X60 mm to zero. Caps, fingers and camera
are not yet installed. Carriages carry their three preloaded nuts as a rigid
cluster; this assumes temporary retention, not a validated nut-loading operation.

| Stage | Moved bodies | Previously installed obstacles | Full pair count |
|---|---:|---:|---:|
| G3_R carriage and nuts | 4 | 248 | 992 |
| G3_L carriage and nuts | 4 | 252 | 1008 |
| G4_R link | 1 | 256 | 256 |
| G4_R washers | 2 | 257 | 514 |
| G4_L link | 1 | 261 | 261 |
| G4_L washers | 2 | 262 | 524 |

The two right-side pivot bolts are added after the right washers, before the
left link. They remain obstacles for subsequent operations. The left bolts
follow the left washers. Final occurrence identities and shape instances match
all266 occurrences of the previously reviewed G4 tool stage, not only its count.
All3555 mover/obstacle pairs are accounted for without duplicates or omissions.
Each stage's total continuous-volume upper bound is0.0 mm3 under the declared
nominal CAD and methods; the unchanged acceptance threshold is1e-4 mm3 per stage.
Washer seating includes contact, so this is not a positive-clearance claim.

```bash
rtk proxy uv run python -m scripts.review_pg3_slider_link_insertion \
  outputs/pg3-installable-candidate-r4 --out outputs/UNUSED-slider-link-insertion.json
```

Evidence: `outputs/pg3-installable-candidate-r4-audit/slider_link_insertion_r1.json`.
Workdoc section29 records hashes, source archive and18 focused passing tests
(the five new tests were also rerun after a lint-only loop cleanup).
No shared checker or CAD geometry was changed. The prior full275-test result
is not a new full-suite run. Exit2 and `installation_approved=false` remain.
G5/G6 body paths are covered separately below. Nut loading/retention, internal
cluster fit, actual screw insertion/threads, hands, cables, physical printed fit
and other arm poses are not approved by these six path checks.

### Sequential Cap And Finger Body Insertion

`scripts/review_pg3_cap_finger_insertion.py` continues from the266-part G4 stage.
Upper cap, its two washers, lower cap, its two washers, right finger, its two
washers, left finger and its two washers each enter from world+X60 mm to zero,
at fixed orientation in the saved r4 mid pose. Two corresponding bolts are
installed after each washer stage and remain obstacles for all later stages.
All earlier parts remain present; pads and camera are installed later.

The eight stages contain266/534/271/544/276/554/281/564 mover-obstacle pairs,
3290 total. Every stage has a0.0 mm3 summed nominal continuous-overlap upper
bound, against the unchanged1e-4 mm3 per-stage threshold. The final286 occurrence
names and shape instances match the G6 tool-stage inventory. Cap hardware side
assignment is also tested against saved world-Y coordinates, not names alone.
Seat contacts retain UNPROVEN distance certificates alongside successful whole
boundary translation-cover certificates. This does not establish positive
clearance, low assembly force, preload or printed fit.

An actual saved upper cap displaced0.5 mm into the frame is rejected: the
continuous upper bound is414.0 mm3, and the final-pose Boolean diagnostic finds
277.6907304 mm3 intersection. The negative control is a test copy, not a CAD edit.

```bash
rtk proxy uv run python -m scripts.review_pg3_cap_finger_insertion \
  outputs/pg3-installable-candidate-r4 --out outputs/UNUSED-cap-finger-insertion.json
rtk proxy uv run pytest -q tests/test_pg3_cap_finger_insertion.py
```

Evidence: `outputs/pg3-installable-candidate-r4-audit/cap_finger_insertion_r1.json`.
Workdoc section30 contains input/source hashes and archive verification.
The focused related run had24 passing tests; after adding the saved-geometry
negative control, all7 new tests passed. No new full-suite or simulation run is
claimed. Exit2 and `installation_approved=false` are intentional. Pad insertion,
nut loading/retention, actual fasteners, hands, cables, physical tolerances and
other arm poses remain separate gates; actual installation DoD remains open.

### Pad Placement Without Sliding The Bond Face

The donor specifies two28x20 mm sheet pads, **1 mm total thickness including
adhesive**, centred vertically and ending1 mm behind each finger tip. The saved
r4 pads retain that envelope. A1 mm sheet plus an additional glue layer is not
automatically equivalent; changed cured thickness requires rechecking opening,
closed-end contact, grasp position, backing and assembly paths.

`scripts/review_pg3_pad_insertion.py` continues after the286-part G6 stage. In
the saved fixed mid pose, move the right pad through these world offsets from
its final location: `(60,0,3)` -> `(0,0,3)` -> `(0,0,0)` mm. The left pad uses
negative Z offsets instead, with the installed right pad retained as an obstacle.
This keeps the bonding face3 mm from its finger during the forward insertion,
then approaches normally. It does not drag an exposed adhesive face along the
finger. The3 mm offset is a checked part path, not a hand/tool clearance claim.

All four continuous segments account for1146 mover/obstacle pairs. Each segment
has a0.0 mm3 nominal summed overlap upper bound. Normal seating includes contact:
the distance certificates remainUNPROVEN while the complete-material translation
covers establish the volume bound. The final288 identities and shape instances
match every non-camera occurrence. A direct60 mm normal approach is a rejected
control because it crosses the opposite finger; a saved-pad copy at the18 mm
intermediate offset has more than100 mm3 measured intersection with that finger.

```bash
rtk proxy uv run python -m scripts.review_pg3_pad_insertion \
  outputs/pg3-installable-candidate-r4 --out outputs/UNUSED-pad-insertion.json
rtk proxy uv run python -m scripts.render_pg3_pad_insertion \
  outputs/pg3-installable-candidate-r4 --out outputs/UNUSED-pad-insertion-views
```

Evidence is in `outputs/pg3-installable-candidate-r4-audit/pad_insertion_r1.json`
and `pad_insertion_views_r1/manifest.json`; workdoc section31 records provenance.
At the G7 checkpoint, the12 new tests and37 related tests passed; its full
repository run was310 passed. The current full regression is listed above.
All six headless VTK waypoint images were visually inspected and checked for
nonblank moving-pad pixels. Green is the pad being installed, black is a previously
installed pad, orange the fingers. The-Y view is intentionally cropped; the
numerical check, not that crop, covers all installed obstacles. Camera installation
follows this stage and is not shown in these views.

The pad material, adhesive, release liner, positioning/pressure tooling, PLA
bond compatibility, cured strength and gripping friction remain unconfirmed.
These path checks do not approve bonding or physical assembly. They do not alter
the frozen CAD, resolve the P05 cable exit, or promote the installation DoD.

Across the saved G1/G2, G3/G4, G5/G6 and G7 reports,20 body-path segments contain
10116 mover/obstacle pair checks. This is a count across segments, not10116 unique
physical contacts or a whole-arm motion certificate. Every nominal segment has
its own accepted volume bound under its stated assumptions; all four reports
retain `installation_approved=false`. Preloaded nuts and later bolts still need
their own loading/retention/thread evidence. The separate camera-body path check
is not included in this count, and actual bonding is not closed by G7.

### Nut Loading Is Not Nut Retention

`scripts/review_pg3_nut_loading.py` checks the12 PG3 nuts before their hosts are
installed on the arm. Four separate bench clusters match the existing G1/G2/G3
body inventories: frame+four cap nuts, crank/spacer+two drive nuts, and each
carriage+two finger nuts+one pivot nut. Nuts enter sequentially along world-X30 mm
to zero. Previously loaded nuts remain obstacles within each cluster. The27 full
pair checks cover these bench clusters, not hands, fixtures or an installed arm.

The original rectangular swept cover and distance methods leave all12 paths
UNPROVEN. The supplement constructs a hexagonal prismatic enclosure using six
whole-B-rep support bounds. Rotated B-rep extrema include curved bulges between
vertices; each support and axial endpoint is padded outward1e-7 mm. A bounded,
consistent convex polygon and extended X interval enclose the entire source
throughout translation. The nut centre hole is conservatively filled in this
enclosure only; no source geometry is healed or altered.

Both world-space and an explicit common rigid coordinate re-expression are
checked. The world check retains25PASS/2ERROR; the re-expressed check has27PASS.
The original crank self-Boolean errors remain visible. All12 supplemented
nominal paths have a0.0 mm3 summed intersection upper bound, against the unchanged
1e-4 mm3 per-stage limit. Four mounting families displaced0.2 mm into their seats
are rejected. An adversarial curved bulge is enclosed even though its maximum
extent is not a topological vertex.

Evidence: `outputs/pg3-installable-candidate-r4-audit/nut_loading_r2.json`.
The earlier r1 result and both source snapshots remain available; workdoc
section32 lists hashes. At the nine-test checkpoint,28 related tests passed.
After extending the seat-intrusion controls to four families, all12 new tests
passed. The full run then remained the earlier310-test checkpoint; the current
full regression above now includes these tests.

```bash
rtk proxy uv run python -m scripts.review_pg3_nut_loading \
  outputs/pg3-installable-candidate-r4 --out outputs/UNUSED-nut-loading.json
```

The reverse of each accepted nominal path is available in the same bench state.
A hex pocket can prevent rotation without providing axial retention. This does
not predict friction or falling under gravity, and it does not prove access after
mounting the host. Temporary retention during transport/body insertion must still
be specified and checked. Press-fit friction, tape, glue and an unmodelled fixture
are not accepted by assumption. Additional thickness, thread contamination and
removal access must be checked if a holding method is selected. Camera nuts are
outside this PG3 check. No static whole-assembly or full-motion gate is silently
closed by this fixed-mid bench result; installation remains unapproved.

### Loading Nuts Immediately Before Fastening

`scripts/review_pg3_nut_late_loading.py` tests an alternative to transporting
hosts with loose, preloaded nuts. At the saved mid pose, the earliest-host context
checks2955 pairs. The stricter `fastening_envelope` context keeps every non-camera
occurrence except the target nut and its bolt:286 obstacles per nut,3432 pairs.
This is an access bound over a same-pose superset, not proof that the entire
assembly can already be fastened in that order. The camera is installed later.

Both contexts supplementally clear9 nominal -X30-to0 nut paths with zero volume
upper bound: the4 cap nuts,4 finger nuts and left carriage pivot nut. Raw Boolean
errors remain recorded. Actual nut tolerance, hand/holding/driver access and
fastener engagement are still separate gates.

Three paths are not approved:

- Both drive nuts: an actual nut displaced-X1.3 intersects the frame by
  1.07148138 mm3. The five coarse path samples alone miss this narrow obstruction.
  The left path also retains motor/surface ERROR/UNKNOWN results.
- Right carriage pivot nut: the actual nut at-X7.5 intersects P06 by
  1.86915691 mm3, increasing to3.14805374 mm3 at the sampled-X15/-X22.5/-X30
  positions. Case fastener envelopes also obstruct portions of the path.

These are failures of a specific straight path, not proof that every assembly
sequence or lateral route is impossible. Conservative total overlap bounds in
the reports are not measured material penetration volumes.

For the drive nuts, using the existing screw temporarily without the large washer
is a candidate only. The saved screw head is3.8 mm against a5.4 mm link bore;
seating it temporarily requires-X0.5 mm from its final position. These dimensions
do not prove insertion, thread engagement, capture during washer exchange or
tool access. No temporary screw arrangement has been adopted in the frozen CAD.
The right carriage nut needs its own alternative procedure.

Evidence: `outputs/pg3-installable-candidate-r4-audit/nut_late_loading_r2.json`
(r1 is the earlier-host context). Workdoc section33 records the hashes, negative
controls and next checks. Related nut-loading tests:20 passed, including8 new
tests. That check preceded the current full-suite rerun listed above.

```bash
rtk proxy uv run python -m scripts.review_pg3_nut_late_loading \
  outputs/pg3-installable-candidate-r4 --context fastening_envelope \
  --out outputs/UNUSED-nut-late-loading.json
```

The command deliberately exits2: installation is still unapproved.

### Existing Drive Screws As Temporary Nut Holders

The candidate in `scripts/review_pg3_temporary_drive_screws.py` keeps both existing
drive screws, but temporarily removes their large washers and seats the screw
heads directly on the printed shoulders. The only geometry change in this check
is a rigid-X0.5 mm displacement of each saved screw; frozen CAD is unchanged.

Measured at saved mid: head seating area7.186393195 mm2, smooth nut-span overlap
1.6 mm, tip protrusion0.9 mm beyond the nut, tip at worldX19.6 mm and head seat at
X29.6 mm. Both heads clear the link bores by0.8 mm radially. This is nominal
geometry, not evidence of actual thread engagement or permitted tightening torque.

Keeping the temporary screws throughout, the checked order is:

1. Insert the crank/spacer/drive-nut cluster with both temporary screws, then
   install the four horn screws.
2. Insert the right and left carriage clusters.
3. Insert the right and left links, **before adding any pivot-retainer washers**.

All5 +X60-to0 body paths pass the existing1e-4 mm3 volume-bound criterion over3973
mover/obstacle pairs. G2 has a2.003730515e-9 mm3 conservative upper bound; the
other4 have zero bounds. No arm/motor/previous temporary screw is deleted.
The9 internal temporary-screw contacts yield7PASS/2ERROR in world coordinates;
the explicit common rigid re-expression gives9PASS. Raw errors remain recorded.

Negative controls detect real frame penetration with a0.5 mm longer tip and
blocked link insertion with a washer-sized head. Seven new tests pass; the latest
related20-test run passed in54.66 seconds.

This is **not an approved complete assembly instruction**. Material paths for
initial screw insertion and final washer exchange now have supplemental evidence
below. Actual threads/PLA loading, nut retention during exchange, hands/tools,
and the right carriage nut still need checks. Canonical carriage
clusters retain preloaded nuts as occupancy; their physical holding is not proved
by moving the cluster mathematically. Large washers remain mandatory in the
final assembly. Do not operate the gripper in this temporary state.

Evidence: `outputs/pg3-installable-candidate-r4-audit/temporary_drive_screws_r1.json`.
Workdoc section34 records source/input hashes and the next unresolved steps.

```bash
rtk proxy uv run python -m scripts.review_pg3_temporary_drive_screws \
  outputs/pg3-installable-candidate-r4 --out outputs/UNUSED-temporary-drive.json
```

Exit2 is deliberate because installation remains unapproved.

### Temporary Screw Loading And Final Washer Exchange

`scripts/review_pg3_drive_screw_exchange.py` adds8 fixed-mid paths: bench loading
of each temporary screw, followed (after the separately checked body stages) by
right screw removal, right washer insertion, right final screw insertion, then
the same three left operations. The right final screw stays installed during the
left exchange. Both links, the arm, motors and the opposite screw remain obstacles.
Final drive bolts/washers are the exact saved shapes, not the temporary placements.

All1568 physical mover/obstacle pairs are checked in world coordinates and an
explicit common rigid frame. A two-cylinder material bound supplements12 close
bolt/receiver pairs: it verifies whole-bolt containment, examines every obstacle
boundary face and retains numerical padding and containment residuals. It does
not infer a through hole merely from a cylindrical face or discard a blind floor.
The bound is uniform over all translation parameters, not a proof about the
union swept by containment residuals. All selected pair bounds are summed before
applying the existing1e-4 mm3 criterion.

Both bench loading paths and temporary screw removal paths have upper bounds
about3.447899e-6 mm3; final screw insertion about3.518585e-6 mm3; washer paths zero.
All8 paths pass this **nominal material-intersection bound**. This is not exact
zero intersection or positive running clearance. Raw UNPROVEN/ERROR results
remain alongside the supplemental proof.

Thirteen focused tests reject head intrusion, axis misalignment, blind bores,
uncovered material, missing arm obstacles, invalid travel and aggregate tolerance
overruns. A diagnostic penetration vetoes acceptance even if another proof claims
a clear bound. The latest related run is20 passed in43.83 seconds.

**Retention remains a prerequisite, not a result:** the nuts and links are fixed
at their saved positions in this check. Physical nut capture while a screw is
absent, hand support, actual thread engagement and driver rotation/access still
need verification. Reversing a smooth proxy translation does not simulate
unscrewing a real threaded fastener. Installation is not approved.

Evidence: `outputs/pg3-installable-candidate-r4-audit/drive_screw_exchange_r1.json`;
source snapshot and hashes are recorded in workdoc section35.

```bash
rtk proxy uv run python -m scripts.review_pg3_drive_screw_exchange \
  outputs/pg3-installable-candidate-r4 --out outputs/UNUSED-drive-exchange.json
```

The command exits2 deliberately; never overwrite a previous evidence file.

### Bench-Preassembled Linkage Alternative

Before designing extra in-situ nut keepers, a different order was checked with
`scripts/review_pg3_bench_cluster.py`. Bench-fasten the crank, two carriages and
two links with all four final pivot bolt/washer/nut sets:17 components. Hold that
articulated mechanism and the separate horn spacer at the saved mid geometry,
translate the18 parts into the already-mounted frame, then install the4 horn screws.
The4 finger nuts are loaded later using the separately checked access paths.
G1 cap nuts remain conservative stationary obstacles in the insertion check.

The18-by240 insertion scan covers4320 pairs with a2.003730515e-9 mm3 total bound
(below the existing1e-4 criterion, not exact zero). All144 bench pivot-tool pairs
and2096 final horn-tool pairs pass. Both access and withdrawal envelopes are kept;
final washers are already installed rather than removed to simplify the path.
Six focused tests reject an omitted frame, moved link, missing last-screw tool
and a wrong-side approach with actual frame penetration.

Compared with the temporary-screw sequence, this moves all four pivot nuts,
including the obstructed right carriage nut, to an exposed bench operation.
It can eliminate both drive screw exchanges. The tradeoff is holding an articulated
mechanism at its insertion pose and supporting the **uncaptured separate spacer**.
The checker does not prove that the mechanism is rigid, that hands/fixtures can
hold it, or that the bench fasteners can be loaded/held and tightened in practice.
The four horn screw insertion/thread interfaces remain separate from tool access.
Previous intra-cluster contact and actual hardware/print gates are not waived.

Bench support also needs attention: drive nut rear faces are at worldX20.5 mm,
carriage nut rear faces atX22.85 mm. A single flat surface does not support them
equally. Their screw tips are atX20.1 andX22.1 respectively, so support must leave
tip clearance. These are measured saved-CAD values, not a validated fixture design.

Evidence: `outputs/pg3-installable-candidate-r4-audit/bench_cluster_r1.json`.
Four headless views in `bench_cluster_views_r1/` show the held18-part state,
not a complete arm or a physical holding method. Workdoc section36 records hashes,
visual inspection and the comparison with the former sequence.

```bash
rtk proxy uv run python -m scripts.review_pg3_bench_cluster \
  outputs/pg3-installable-candidate-r4 --out outputs/UNUSED-bench-cluster.json
```

Exit2 remains deliberate: neither this path/tool result nor a short assembly
sequence satisfies the actual-installation DoD by itself.

## Design Contract

PG3 C92 J28 C9 source archive is unchanged. The candidate frame has only the four
local reliefs specified below; mechanism, fingers, motor alignment and the
25-135 degree *relative mechanism* interval are retained. This
interval is not an absolute servo command range. Physical ID5 remains reserved
for wrist roll; the gripper's bus ID has not been assigned by this CAD work.
No hardware is energized or commanded.

### Local PG3 Frame Relief In r4

In **PG3 construction coordinates**, remove only the four combinations of
X[-46,-44]/[44,46], Y[-18.8,-18.5]/[18.5,18.8], Z[19.5,24.1] mm.
Total removed material is11.04 mm3; addition and removed material outside that
mask are both0. Frame volume12645.914126 ->12634.874126 mm3. The result is one
valid solid with a watertight, connected STL. Motor/cap bores and their seating
regions, main rails and outer envelope are retained. Each end land retains
2 x3.2 x4.6 mm material, not a strength qualification.

The replacement is `changed_parts_CANDIDATE/PG3_frame_guide_relief.{step,stl}`.
Do not use the copied original `01_frame` for this candidate. `review.json`
contains the explicit replacement map; original PG3 copies are reference-only.
The replacement part uses construction coordinates; its assembly placement is
Ry(+90deg), then translation(-0.2,234.9,164.6) mm, identical to the original.
`r4-audit/guide_relief/guide_relief.json` verifies all three saved assemblies
contain this exact saved replacement using controlled bidirectional differences.
Its eight separate before/after PNGs show the four end lands without overlay.

P05 and upstream arm links are unchanged. P06 is retained as a motor support;
removing it entirely is prohibited. The candidate is derived by subtraction from
the original B-rep, not a newly guessed outline. In R3 world coordinates (mm):

| Local P06 change | Purpose | Preserved |
|---|---|---|
| Remove Y >= 240.9 | Delete obsolete distal fixed finger | Motor support and mounting-hole zone |
| Trim X >= 16.3 | Leave 0.5 mm nominal gap to PG3 frame | Upstream horn seat and bottom screw load paths |
| Four bottom bores 2.4 -> 2.8 mm | Clear M2.6 case tapping screws | Centres, support thickness and seating plane |
| Lower horn rear counterbore, diameter4.8, Y187.9..192.0 | Open the original blind lower bore and seat a spacer | Front seat Y183.9, centre(-0.2,156.6) in XZ, diameter2.4 through 4 mm wall |

No addition outside the original part. Hole centres are (-6.2 or 5.8, 206.9 or
230.9), axes +Z. Case seating plane Z150.35; support underside Z146.35.
Original frame intersection: 240.5625 mm3. Revised intersection: 0; gap: 0.5 mm.
The final P06 volume is 9089.691818072772 mm3, one valid solid. Earlier volumes
9122.1193 and9148.2573 precede the rear counterbore and case-bore corrections.
All changes lie inside the four explicitly declared change masks. The rear
counterbore is a local fastening repair, not permission to remodel the link.

The side camera carrier origin is (52,53,164.6), with +Y-facing reference camera.
The bracket joins the existing P05 clamp and a replaceable 28 x 28 mm carrier.
Only the left cable-tie ear is removed because it occupied the right M3 clamp
screw region. The right tie anchor remains. The camera model, cable, actual
optical origin/FOV and mass still need confirmation against the purchased part.
The current bridge spans Y49..140.4 (91.4 mm), X26..58, Z193.6..199.6.
This is a longer rear-set cantilever, not the earlier short bracket. Its stiffness,
PLA creep and vibration are unverified; better framing is not mechanical approval.

In candidate r3, a broad root roof spans X[-23.2,58], Y[130.4,144.15],
Z[196.6,202.6]. The old bridge joined the saddle over only60.9 mm3.
The new saddle volume is27191.15443 mm3 (previous22452.65443). This local
fixture addition preserves P05, camera pose and clamp seats. It increases the
load-path section but is not a calculated strength or PLA-creep approval.

### Wiring Blocker And Corrected Exit Interpretation

The nominal9.5 x3.8 mm EHR-3 plug access cross-section, swept40 mm straight
backward from M05's rear plane, intersects original P05 by144.4 mm3 per port.
It also intersects the camera saddle by37.905 and front jaw by27.075 mm3 per
port. A long straight approach encounters M04 hardware too. These are blocked
**access corridors**, not claims that the installed connector penetrates P05.
The source header geometry is used to locate each corridor; another arm/header
pose is rejected rather than reusing these fixed rear planes.

**Correction:** that straight corridor is not the normal assembled cable exit.
The official XL430 assembly figure removes the rear cover to route wires via
the side outlet or hollow idler shaft, then reinstalls the cover. See
`references/robotis-xl430-cabling/SOURCE.md` and the pinned supplier images.
The3.5 mm rear gap therefore does not define every possible cable route. Do not
justify cutting P05 solely by the hypothetical straight-corridor failure.

The [official XL430 product page](https://en.robotis.com/shop_en/item.php?it_id=902-0135-000)
also limits the hollow-case route to one cable (checked2026-09-23). A future
central P05 relief must not be used to justify passing both daisy-chain cables
through that route. The second harness needs a separately validated side exit.

The corrected first-lateral-leg diagnostic uses six separate1.9 mm wire envelopes
and assumed1.2 mm centreline bends. It avoids wire-to-wire overlap but intersects
P05 at both side outlets:5.52881 mm3 per wire, X14.05..16 or-16.4..-14.45,
Y149.65..151.55. The nominal motor/host lateral gap starts at only0.1 mm.
It also overlaps rear-cover corners by0.11463..0.12584 mm3 per wire; the assumed
route is rejected, not squeezed into a fit. There are1851PASS/6UNKNOWN/12FAIL
in `r3-audit/wire_side_outlet_r1/routes.json`.

The hollow-axis alternative is also obstructed by the unchanged P05 back plate:
a diagnostic radius3 cylinder along the rear axis(-0.2,Y,164.6), Y137..147,
intersects113.09734 mm3, equal to a full4 mm wall. Thus the candidate host needs
further wiring design even with the standard preassembly sequence. This does
not prove all possible free-form routes impossible. No actual cable bend limit
has been established. P05 has NOT been cut; permission for a minimal local
relief/reprint was requested again with this corrected evidence.

The public JST drawing, dimensions, source links and hash are recorded in
`references/jst-eh/SOURCE.md`; actual cable dimensions and bend radius are unknown.

## Fastening Candidates

The following are explicit procurement/fit candidates, not claims of purchased
or measured fasteners. Full release requires the actual head, washer, thread
form and tool to satisfy these envelopes and the assembly test.

| Joint | Candidate and quantity | Stack / verification |
|---|---|---|
| P06 -> M06 case side | 4 x ROBOTIS S14 PHS M2.6x8 TAP K, 4 x washer ID2.8/OD7/t0.5 | 4 mm PLA + 0.5 washer; penetration3.5, max4, bottom margin0.5 mm |
| Camera -> carrier | 4 x M2x10 + M2 nuts | Candidate grip6.5, nut1.6, tail1.9 mm |
| Carrier -> bracket | 2 x M2x10 + captive M2 nuts | Candidate grip7, nut1.6, tail1.4 mm |
| P05 clamp | 2 x M3x16 + M3 nuts | Candidate grip10, nut2.4, tail3.6 mm |
| P06 -> M05 horn | 4 x M2x8 socket head (max diameter3.8/height2), 4 x metal spacer ID2.2/t1 | PLA4 + spacer1 -> engagement3, bottom margin0.5 mm. Three spacers OD5; lower spacer OD4.3 |
| PG3 mechanism | Original C9 fasteners retained | See source assembly instructions; integration scan does not certify thread preload |

**Do not replace side-hole tapping screws with the M2.5 case assembly screws.**
The original 2.4 mm P06 bores obstruct the 2.6 mm shank (3.14159 mm3 per bore).
Revised 2.8 mm bores give 0.1 mm nominal radial clearance before printing effects.

Sources: [ROBOTIS XL430 drawing](https://www.robotis.com/service/download.php?no=772),
[side-hole screw package specification](https://en.robotis.com/shop_en/item.php?it_id=902-0135-000),
[S14 dimensions/name](https://www.robotis.com/shop/item.php?it_id=903-0183-000).
The S14 product listing establishes nominal screw designation, not measured head
dimensions or load capacity in this assembly. Official PDF/STEP and SHA256 are
retained in `references/robotis-xl430-new-20180324/`.

Actual M06 concave bore axes are independently extracted from the mating CAD.
Their cylindrical spans are Z150.55..154.35; the first 0.2 mm is the entry region.
`case_attachment_report` rejects a 1 mm misplaced motor and M2.6x5/M2.6x10
with the declared stack. Minimum3 mm engagement is a candidate design target,
not a validated pull-out or creep limit.

The upstream horn actual seat is Y183.9 (source face186); the case actual seat
is Z150.35 (face98). These are planar-face measurements, not inferred from bore
length. Axial seat-gap negative controls reject a motor shifted along its bore.
The lower original horn bore was blind: a cylindrical span ending atY189.9 did
not mean the material ended there. The rejected M2x10/spacer arrangement collided
with the original rear material. The local counterbore gives a common4 mm grip
for four M2x8 screws. All bolt/spacer vs revised P06 intersections are zero.
The lower spacer's full material-supported annulus is9.99812 mm2, excluding the
larger support bore, not merely the spacer's smaller ID. No pull-out or clamp-load
allowable is inferred from this area.

### PG3 Pivot Retention

The four original C9 printed-shoulder pivots were remeasured independently in
the saved r3 open/mid/closed assemblies. `r3-audit/pivot_contacts_*.json` records
actual concave/convex cylindrical interfaces and planar face intersections:

| Nominal property | Measured at all four pivots |
|---|---|
| Rear/front axial link gap |0.3 /0.3 mm|
| Radial link-to-shoulder gap |0.2 mm per side|
| Retainer overlap beyond link bore |0.8 mm radial|
| Nut/printed-seat contact |9.70165 mm2|
| Retainer/shoulder contact |15.48020 mm2|
| Bolt-head/retainer contact |7.53982 mm2|
| Bolt tail past nut |0.4 mm drive;0.75 mm carriage|

The clamp path is head -> large retainer -> printed shoulder -> captive nut,
not through the rotating link. These are nominal CAD measurements, not actual
preload, washer bending, print-tolerance, creep or free-motion approval. The
retainers remain OD7/ID2.2/t0.5; smaller general washers are not interchangeable.
The checker rejects displaced links/washers/bolts, a nut0.2 mm inside its seat,
and a headless pin. The latter two incorrectly passed the initial axial-span-only
checker; planar contact and head-geometry checks fixed that false acceptance.
`pivot_stacks_*.json` is the superseded initial local audit; use `pivot_contacts_*`.
No PG3 source geometry or fastener position was changed by this audit.

## Assembly and Service Order

This is a partially verified mechanical sequence, **not yet an executable full
installation instruction**. Resolve M05 wiring access and wire egress first;
do not assemble the link and discover afterward that the plugs cannot be fitted.

1. With power disconnected, support the arm and remove obsolete P07/P06 only
   as needed for replacement. Do not force-turn a geared motor or use torque to
   overcome a tight printed fit.
2. Mount revised P06 to the M05 horn **before installing M06**. Final upstream
   screw candidates are M2x8 with the spacers above. Their nominal straight tool
   corridors are checked; actual tools, hand clearance and insertion remain open.
3. Place M06 on the P06 seat. Fit the four case-side screws/washer candidates
   from below. Stop if a screw bottoms before clamping or deforms the PLA seat.
4. Use the immutable PG3 C9 bench order as the baseline for the frame, horn spacer,
   crank, sliders, links, pivot retainers, caps and fingers. The installed-arm
   refinements above remain partial candidates, not an approved replacement order.
   Prioritize bench fastening of all four pivots, then held mechanism insertion
   and horn fastening, before caps/fingers/pads. Validate bench support and handling
   before adopting it. The temporary-drive-screw sequence is retained as an
   alternative, not a mandatory exchange operation. Keep all large pivot-retainer
   washers in the final assembly; they are functional, not optional cosmetics.
5. Bench stage A: insert the two captive carrier nuts, then attach the camera and
   spacer to the carrier with four M2 screw/nut pairs **before attaching the
   bracket**. Stage B: attach that subassembly to the saddle using two accessible
   M2 screws. A coarse all-M2-after-bracket sequence failed2 tool pairs and is
   retained as a rejected sequence, not silently erased.
6. Seat the camera saddle and front jaw on P05 without squeezing the motor
   cheeks. Tighten the M3 clamp using the validated **nominal short-driver
   envelope**: shaft radius2.5 x exposed25, handle diameter20 x length25 mm.
   A 75 mm shaft plus 30 mm handle intersects the PG3 mechanism.
   The right M3 nut socket additionally requires an exposed100 mm shaft,
   diameter9, with diameter20 x length30 handle. Its former75 mm shaft caused
   441.05 mm3 handle/bracket intersection. These envelopes are procurement
   constraints, not claims that such tools are already on hand.
   At the saved mid arm pose, lower the preassembled16-part camera/saddle cluster
   from60 mm above its final position, then lower the front jaw from above, before
   inserting either M3 screw. The unpowered rigid translation and its reverse have
   a conservative continuous occupied-volume clearance proof. This assumes a
   fixed arm with no cables or hands in the path; it does not certify hand space.
7. For camera service, release the M3 clamp and remove the complete camera
   subassembly upward; undo stage B, then service stage A. The M3 screws must be
   removed first. Other insertion/tool paths, fingers around the handle, and cable
   slack remain to be checked.
8. Route the actual camera cable through the retained tie anchor with strain
   relief, leaving connector access and a measured bend radius. No unverified
   cable envelope has been called PASS.

## Evidence and Reproduction

Historical section27 checkpoint: `outputs/pg3-installable-candidate-r4/`.
For current r5 counts, source selection and images, see "r5 Integration Checkpoint".
Three saved/reloaded assemblies each contain309 occurrences and24795 changed-
context pairs:24735 PASS,50 ERROR,10 UNKNOWN,0 reported FAIL. The ERROR/UNKNOWN
results mean this is **not** an all-clear collision result. Six changed-part
meshes are watertight, consistently wound, connected single components.
Independent r4 artifact checks verified409 hashed files,39 nonblank PNGs and47
GIF frames. Per-channel spatial pixel standard deviation exceeds16.88 for every
PNG; visual inspection also covered the whole assembly and XYZ terminal views.
The section27 checkpoint full regression passed275 tests (364.17s), including finite-cylinder
crank fastener checks and explicit retention of an unproven screw, controlled
motor partition boundaries, nominal washer seating and invalid-evidence guards,
trimmed-arc horn enclosures, whole-host pivot
clearance, source-guarded axial separation, local-relief, saved-part continuous-
clearance, root-roof, mating-region, cable and pivot tests (eight existing
Assembly.save warnings).
Lint passed. The displaced-header guard has a
RED-to-GREEN record; route tests include an explicit wire-to-wire collision.
These are software checks, not a physical installation certificate.
The latest full-suite checkpoint is section42 (392passed); section38 has47
focused regression tests. The section36 result (356passed) and historical
275-test paragraph are not the latest implementation-wide status.

The r4 supplemental directory is `outputs/pg3-installable-candidate-r4-audit/`:
`guide_relief/` verifies the saved local change and all three installed frames;
`occlusion.json` repeats the nine-pose visibility diagnostic with the historical
r4 scene; it predates the installed-frame mesh-source correction in section42.
`continuous_opening_r2.json` records the current fixed-arm opening certificate;
both continuous-checker snapshots match their own r1/r2 report hashes.
`pivot_motion_r1.json` supplements four whole-host/link pairs with negative controls.
Its `pivot_motion_r1_sources.tar.gz` preserves111 code/test/lock files; archived
checker/dependency bytes match the report. This is a source backup, not a complete
CAD input bundle or a manufacturing release. See workdoc section22.2 for its hash.
`horn_sweep_r1.json` adds two complete-spacer rotation certificates.
`horn_sweep_r1_sources.tar.gz` preserves its code/test/lock snapshot; checker and
all eight dependency hashes match. See workdoc section23 for the evidence and hash.
`washer_contacts_r3.json` adds nominal seating evidence, while
`pivot_stacks_{open,mid,closed}_r1.json` remeasure all four pivots in r4.
The124-entry `washer_contacts_r3_sources.tar.gz` includes the matching checker,
all seven dependencies, tests and lock file; workdoc section24 records its hash.
At+/-30 degrees roll the less-visible pad fractions remain89.24% open,
13.08% mid and5.23% closed; these are pad silhouettes, not a grasped-object ROI
or actual-camera calibration. A nonzero silhouette is not useful-image approval.

### Occluding Parts Identified

`outputs/pg3-occluders-r1/review.json` attributes the isolated pad silhouette
pixels to the nearest rendered geometry at the same optics and pose. It verifies
the frozen scene and309 mesh hashes, uses integer segmentation without MSAA,
and reproduces all18 existing visible/reference pixel counts at nine poses.
There are no unclassified pixels. No camera, holder or other CAD was moved.

At opening135/roll+30, the left pad has73 visible pixels out of1396; all1323
hidden pixels are blocked by `PG3_finger_L`. The right pad has546/1476 visible;
`PG3_finger_L` blocks860 and `PG3_pad_L` blocks70. At opening90/roll+30, the
left finger blocks917 of1055 left-pad pixels. Roll-30 mirrors the sides.
At roll0 both pad silhouettes are fully visible at all three sampled openings.

Thus the measured **pad-region** occlusion is due to the fingers/pads, not the
P05/P06 support or camera holder. This does not prove those structures never
occlude another object or ROI. Removing bracket material alone cannot cure this
particular occlusion. Viewpoint selection needs a defined grasped-object ROI,
object dimensions and required roll range; full visibility of both entire pad
silhouettes was never a confirmed user requirement. Actual lens/optics remain
unknown, so this diagnosis neither releases the present mount nor authorizes an
unrelated redesign. RGB and classified masks are saved beside the report.

The following supplemental measurements belong to **historical r3** in
`outputs/pg3-installable-candidate-r3-audit/`. Unless explicitly labeled r4,
do not promote them to validation of the entire current assembly.
Saved r3 attachment geometry passes. Both straight camera insertion paths retain
their conservative continuous-clearance proofs. The nine-pose occlusion audit is
unchanged from r2: roof reinforcement did not improve or worsen the measured pad
silhouette fractions. `mating_regions_mid.json` proves P06 versus an all-face
M05 material cover and PG3 spacer versus a horn cover clear. It also proves eight
nominal screw envelopes clear outside their explicitly bounded mating regions.
The M2.6 forming region is intentionally larger than the pilot; this is NOT
zero thread/material contact or proof of thread strength. Unsupported protruding
face types, displaced joints and over-deep screws fail closed.
The original50ERROR/10UNKNOWN per pose is retained, not overwritten by these
local supplemental proofs. `connector_access_pose_checked.json` records the
remaining wiring obstacle; its result is1220PASS/2ERROR/6UNKNOWN/8FAIL.

Historical supplemental audits remain in `outputs/pg3-installable-candidate-r2-audit/`:
`attachments.json` checks actual axes, seat gaps, fastener/P06 overlap and bearing
areas, and confirmed exported modified parts matched that historical run's geometry.
`service_stages.json`: A104/B32/C1236/D756/E1236 tool pairs PASS. A/B are the
separate bench stages; C is camera clamp on arm; D is horn before M06; E is case.
These reports do not claim hand clearance or continuous insertion proof.
The frozen r2 coarse bench report retains208 PASS/2 FAIL; the explicit A/B
sequence supersedes that sequence, not its recorded measurements.
Kinematic closure error6.641e-12 mm; pad-gap error4.168e-12 mm.

The old r1 camera cropped pads at roll. The revised physical mount was checked
at299 opening/roll samples (opening25..135 and roll-30..30, both5 degree steps).
Minimum projected pad margin42.9884 px in640x480; minimum visible pad area73 px.
Old r1 had166 failed pad observations and minimum margin-137.17 px. The new
framing/nonzero-visibility benchmark passes, **not the actual imaging DoD**:
partial occlusion remains visible and73 pixels can be inadequate for useful
grasp observation. The required roll range and actual optics are unresolved.
`camera_grid/camera_range.json` binds the scene XML and all309 mesh hashes;
XML equality alone cannot prove identical geometry. Segmentation uses explicit
offsamples=0 after MSAA edge IDs caused a renderer exception. No IDs were clamped.

The frozen r2 provenance predates stronger axial seat-gap checks and the explicit
A/B tool-stage helper. Nominal geometry did not change. Supplemental audits
document this distinction; neither historical report nor snapshot was overwritten.

### Supplemental Contact and Insertion Review

The same audit directory contains the following later reports, tied to saved r2
assembly hashes. They do not overwrite the original collision report:

- `contact_triage.json`: each pose's60 unresolved pairs comprise32 supplier-
  internal/partitioned-motor pairs,14 inherited PG3 joints,1 modified P06/motor,
  4 new horn screw/thread,4 new case tapper/pilot,5 camera/mount pairs. The46
  inherited pairs match source signatures, not a proof of harmless contact.
- `components.json`: split operands into **all** existing solids, without healing
  or discarding shells, and test their complete Cartesian product. The5 camera
  pairs are clear with aggregate intersection upper bound0 mm3. Each pose still
  has55 unresolved pairs. The original50ERROR/10UNKNOWN remains intact; five of
  its errors now have independent component-level clearance evidence.
- `occlusion.json`:9 poses, identical optics and meshes with/without occluders.
  At roll30, the less-visible pad silhouette is89.24% at opening25 degrees,
  13.08% at90, and5.23% at135. Zero roll gives100% of both silhouettes. These are
  whole-pad silhouettes, **not contact-face or grasped-object visibility**.
  Do not redesign solely to maximize this proxy; actual objects/optics matter.
- `insertion.json`:61 points on each camera/clamper +Z60-to0 insertion path.
- `continuous_insertion.json`: the original solid plus swept AABBs of every
  boundary face conservatively covers its continuous translation. Camera cluster:
  4607 continuously separated pairs and1 near pair; front jaw after cluster:
  303 separated pairs and1 near pair. Both near pairs have0 mm3 overlap upper
  bound (13 and9 controlled cover checks). Exact zero-volume swept boundary
  boxes are recorded; small positive widths are never discarded. The method
  permits touching, not a guaranteed positive fit margin, and does not cover rotation.

Negative controls include a displaced inherited part, penetration in only one
compound solid, mixed solid/surface input, multiplied per-component tolerances,
full/partial occlusion, and a thin obstacle between otherwise-clear sampled poses.
After these supplemental checks:140 tests passed (95.53s), lint and changed-file
format checks passed. Physical installation remains unverified.

```bash
rtk proxy uv run pytest -q
rtk proxy uv run ruff check .
rtk proxy env MUJOCO_GL=egl uv run python -m scripts.review_pg3_installation \
  --out outputs/pg3-installable-candidate-NEXT
```

Use an unused output directory. The command exits2 while installation acceptance
is incomplete. It exports changed STEP/STL, unchanged PG3 donor STEP/print-STL,
the full assembly at three openings, strict changed-context collision reports,
staged tool reports, headless XYZ/isometric images and MuJoCo kinematics.
Changed-part STL remain in assembly coordinates; they are not an approved
slicer orientation or a G-code job. No SD card was modified.

The simulation checks slider-crank closure and image visibility with real CAD
meshes, but uses dummy inertias, zero gravity and no physical contacts. It does
not validate holding torque, friction, PLA strength or contact dynamics.
The camera FOV50 and sensor position (52,85,164.6) are explicit proxies.

## PG3 Tool-Stage Candidate

`scripts/verify_pg3_service_stages.py --mechanism` supplements the original
50 mm shaft-only access check. Stages G1/G2/G4/G5/G6 retain the complete arm
and every previously installed PG3 occurrence. They check all18 screws, including
the target screw as an obstacle. Camera installation C follows these stages;
camera A/B are separate subassembly operations. Pads follow G6.

The generic tool reservation uses a diameter3 x75 mm shaft, diameter20 x30 mm
handle and diameter80 x100 mm grip volume. Each cylindrical segment is extended
by100 mm to cover continuous +X withdrawal, not merely endpoints. These are
declared design envelopes, not measured tools or validated human hand sizes.
The model begins0.05 mm above the screw head and does not prove bit engagement.

`mechanism_tool_stages.json` retains four ERROR results: the static and swept
tools at horn bolts0/1 touch the crank (distance0); its Boolean self-control
fails. This is not a proven positive penetration volume and is not accepted.
With `--horn-l-key`, a separate candidate replaces only the four horn tools.
[PB210.1,5 supplier specifications](https://www.pbswisstools.com/en/tools/quality-hand-tools/precisionbits/product/pb-210)
give1.5 mm AF and14/50 mm inner arm lengths. The candidate additionally requires
at least35 mm straight shank before the elbow/grip region. That requirement is
**not** a published supplier dimension. Its circular shaft cover has radius
1.5/sqrt(3); the elbow turning reservation is radius15 and the grip radius40.
Actual bend geometry, socket engagement, torque rating and human access must
fit these envelopes before adopting this tool.

At the saved r3 mid pose, the L-key candidate's two limiting crank clearances
are0.633975 mm; the other two are2.069575 mm. The candidate run clears all five
PG3 stages (960/1984/2128/2208/2288 tool-obstacle checks respectively).
This is **conditional outer-tool access**, not complete boltability, bolt/nut
insertion, all arm poses or actual assembly approval. Case tapper drive recesses
are not represented in the source CAD and require an actual screw/tool choice.

Latest dimension-labelled report:
`outputs/pg3-installable-candidate-r3-audit/mechanism_lkey_stages_r2.json`.
The earlier report lacks the explicit distinction between inner and overall
arm lengths; geometry is identical, but its checker hash remains historical.

```bash
rtk proxy uv run python -m scripts.verify_pg3_service_stages \
  outputs/pg3-installable-candidate-r3/arm_camera_mid_CANDIDATE.step \
  --mechanism --horn-l-key --out outputs/UNUSED-tool-report.json
```

Exit0 means only the specified nominal tool stages passed. Installation remains
unaccepted regardless of that exit code. Do not overwrite previous reports.

## Supplemental Rigid-Frame Contact Audit

`scripts/review_pg3_local_contacts.py` applies the same inverse arm placement
and inverse drive rotation to both operands. It changes neither relative pose
nor donor geometry, Boolean tolerances or partner inventory. It checks all14
raw unresolved PG3-to-PG3 pairs in each saved assembly, leaving the other46
raw unresolved pairs explicitly outside this supplemental scope.

The first saved-artifact run found six clear pairs at mid and closed: crank
against four horn screws and two captive drive nuts. Independent-copy self-cut
and self-common controls pass in those coordinate representations. Deliberately
moving a horn screw0.5 mm inward produces3.593197 mm3 penetration; moving a
drive nut0.2 mm into its seat produces1.940330 mm3. The eight other PG3 pairs
remain ERROR, not approved threaded contacts.

At the saved open pose, all14 pairs and both negative controls remain ERROR.
The equivalent in-memory generation passed its unit fixtures; that difference
is exactly why the saved artifact is checked separately. No result at mid or
closed is inherited by open, nor does this prove continuous mechanism motion.
`local_contacts_r2.json` in the r3 audit directory records accepted clear pairs
only when that pose's negative controls detect actual penetration. It retains
`all_selected_contacts_clear=false` and `installation_approved=false`.

```bash
rtk proxy uv run python -m scripts.review_pg3_local_contacts \
  outputs/pg3-installable-candidate-r3 --out outputs/UNUSED-local-contacts.json
```

Exit2 is intentional: supplemental pair clearance cannot approve installation.
The original raw collision reports are not rewritten.

### Current r4 Crank Fastener Evidence

The same rigid-frame checker was rerun on frozen r4, producing
`local_contacts_r1.json` under `outputs/pg3-installable-candidate-r4-audit/`.
Mid/closed each retain six controlled clear pairs; open remains14 ERROR.
These are current saved-artifact results, not inherited r3 approvals.

`scripts/review_pg3_crank_fasteners.py` adds a separate whole-material check:
the actual complete screw must lie inside its measured shank/head cylinder
union with zero outside residual. Every crank face is checked over each finite
cylinder's axial span. After excluding all boundary from the connected cylinder
core, an OUT point classification excludes complete containment. The point alone
is insufficient. Controlled face partitions retain all axial surface material;
end slabs consume a summed volume budget, never an implicit zero allowance.
Opposing head/seat normals and common area are checked separately.

Saved open/mid/closed all yield bounded nominal contact for screws1,2,3:
the maximum summed contact-volume upper bound is2.896549482513e-6 mm3,
below the unchanged1e-4 mm3 threshold. Their18 displaced controls are UNPROVEN.
**Screw0 remains ERROR in all three poses**, including its six negative controls,
because crank face5 fails self-control during a required partition. A common
rigid coordinate rotation did not fix it. The whole four-screw report therefore
retains `accepted=false` for every pose. No collision-free assembly claim follows.
The six nuts/bolts accepted at mid by the other method do not clear saved open.

```bash
rtk proxy uv run python -m scripts.review_pg3_crank_fasteners \
  outputs/pg3-installable-candidate-r4 --out outputs/UNUSED-crank-fasteners.json
```

Current report: `outputs/pg3-installable-candidate-r4-audit/crank_fasteners_r1.json`.
Exit2 preserves installation nonapproval. Twelve unit checks include a distinct
fail-closed regression for screw0; their success is not four-screw acceptance.
Neither this bound nor a smooth screw model proves thread engagement, tightening,
PLA bearing strength, nut capture, printed fit or cable clearance. The two drive
nuts remain outside this cylinder method's scope. No geometry was altered.

## PG3 Receiver And Head Seating Audit

### Source-Equivalent Crank Repair Candidate

Workdoc section41 adds `outputs/pg3-crank-representation-r2/`, with three whole-arm
STEP assemblies. The supplied C7 `crank()` construction and dimensions are reused
under a source hash guard, deferring intermediate `clean()` calls until the end.
No hole or outline is redesigned. Controlled comparison of the reimported native
candidate against the original manufacturing STEP gives zero material in both
directional differences (common-volume error 2.046e-12 mm3); both operands pass
independent-copy identity. This is stronger than a volume or vertex-only match.

All three saved installed cranks also pass identity. Each is checked against all
308 other saved occurrences, giving 924 PASS pairs across the three static poses.
All four horn screws have bounded nominal seating; all24 displaced controls are
UNPROVEN, not ERROR. The maximum contact-volume upper bound remains
2.896549482513e-6 mm3 against the unchanged1e-4 threshold. There are no partner
exclusions. These are static crank-partner checks, not whole-arm motion approval.

The earlier r4 ERROR report and original files remain intact. At section41 this
candidate was not yet the installation entrypoint; section42 integrates it into
r5 without granting fabrication release. Current reference
camera, cable-egress, physical fastener and PLA load gates remain unresolved.
The intermediate-clean hypothesis is supported by the construction experiment;
it is not a complete explanation of the kernel's internal defect. Translation,
OBB/non-destructive flags, circular seam rotation, and an isolated2.8.0/7.9.3.1.1
environment did not fix the original input. No dependency update was adopted.

```bash
rtk proxy uv run python -m scripts.review_pg3_crank_representation \
  outputs/pg3-installable-candidate-r4 --out outputs/UNUSED-crank-representation
rtk proxy env MUJOCO_GL=egl uv run python -m scripts.simulate_pg3_saved \
  outputs/pg3-crank-representation-r2 --out outputs/UNUSED-crank-simulation
```

Both commands retain exit2 while installation is unapproved. The simulation reads
the SHA-verified saved poses, not a new source-only build, and checks the kinematic
mapping before rendering. Neither kinematic motion nor nominal contacts prove
thread engagement, assembly preload, strength or camera task visibility.

The saved-candidate simulation completed221 samples with maximum closure residual
6.641072494313e-12 mm and pad-gap error4.168221323653e-12 mm. Evidence is under
`outputs/pg3-crank-representation-simulation-r1/`. All328 output hashes were checked;
terminal and camera-proxy frames were inspected. The candidate/old-checker/frame
regression run has32 passing tests. This does not supersede the section40 full-suite
checkpoint or validate forces and camera visibility.

### Receiver Audit Scope

`scripts/review_pg3_drive_fasteners.py` reads the actual receiver and screw
faces from each saved assembly. Horn material is conservatively covered by its
complete boundary-derived body/boss cover; both case solids remain inside the
case AABB. Potential overlap is allowed only inside receiver-derived cylindrical
regions, not inside an entire motor exclusion. These regions stay fixed when
testing displaced screws.

| Interface | Count | Insertion from seat | Tip/depth-limit gap | Cylindrical-span overlap |
|---|---:|---:|---:|---:|
| Horn M2x6 model | 4 | 2.50 mm | 1.00 mm | 2.30 mm |
| Front case M2.6x5 countersunk model | 2 | 2.65 mm | 1.35 mm | 2.45 mm |

The cylinder-span overlap excludes the0.2 mm entry chamfer, but is **not a
measurement of actual threaded engagement**. Depth ceilings are3.5/4.0 mm from
the pinned ROBOTIS drawing. Minimum remaining bottom margin0.5 mm is a design
check, not a supplier strength qualification. Head/crank planar contact measures
7.186393 mm2 per horn screw. Each case countersink has20.692727 mm2 nominal
contact with opposing outward normals. Equal conical faces on two overlapping
male parts must fail; common area alone was insufficient and was corrected.

The saved open/mid/closed assemblies pass these six **receiver-region and seating**
checks. Reports: `drive_receivers_{open,mid,closed}_r2.json` in the r3 audit
directory. Earlier reports lack the opposing-normal gate and remain historical.
This does not clear the complete crank at open or other motor-internal contacts.

```bash
rtk proxy uv run python -m scripts.review_pg3_drive_fasteners \
  outputs/pg3-installable-candidate-r3/arm_camera_mid_CANDIDATE.step \
  --out outputs/UNUSED-drive-receivers.json
```

The command exits2 because installation remains unapproved. Actual screws,
drive recess, strength, thread form, tolerances and tightening torque still need
their own evidence. The supplier's package list states M2.6x5 tapping screws;
that listing alone does **not** confirm the modeled countersunk head dimensions.
Do not substitute an8 mm internal case screw for this5 mm mounting model.

## Case Screw Procurement Gate

Checked2026-09-23. A nominal diameter/length match is not an approved replacement.

| Candidate | Confirmed fact | Decision / missing evidence |
|---|---|---|
| [ROBOTIS XL430 package screw](https://en.robotis.com/shop_en/item.php?it_id=902-0135-000) | M2.6x5 TAP listed | Preferred compatibility reference; actual head, tip, thread pitch and existing formed-hole condition unknown. Ask for package-screw photos/drawing before adapting the seat. |
| [Supplier item210001010026005001](https://www.tsurugacorp.co.jp/shop/g/g210001010026005001/) | B0 countersunk2.6x5 is listed; listed thread series28 TPI | Availability of a size is not XL430 approval. Lead taper and receiver compatibility unresolved; do not order as a drop-in. |
| [WILCO UF-2606-B1](https://wilco.jp/products/U/UF-B1.html) | Listed2.6x6, head diameter5.2/height1.5 mm, PH1 | Not5 mm; B1 is not automatically interchangeable with the OEM thread. Do not extend the current screw solely to gain engagement. |

[Yahata's tapping-screw explanation](https://yht.co.jp/column/240514_tapping-screw/)
describes a2..2.5-turn tapered lead for B0. As a **conditional screening example**,
retain the current CAD seating/insertion2.65 mm, assume28 TPI (pitch25.4/28 mm),
entry relief0.2 mm, and no other unthreaded neck/bottom relief. Then full-form
axial overlap is only0.182143..0.635714 mm, not2.65 mm. This is an inference
under declared assumptions, not a measurement of an OEM screw or its strength.
It fails an illustrative1 mm full-form screening target; that target itself is
not an approved load/strength criterion. A different head profile changes seating
and invalidates even this conditional estimate.

`gripper_design.serviceability.check_fastener_stack` now distinguishes tip
insertion from full-form overlap. Four incomplete-thread dimensions must be
provided explicitly; unknown values remainUNKNOWN rather than becoming zero.
It intersects the screw's full-form interval with the receiver's usable interval,
checks bottom clearance separately, and rejects NaN dimensions. AnyPASS from
this function still leaves thread strength unverified. The older raw CAD
receiver reports remain geometric evidence only, not procurement approval.

No screw, motor pilot hole, countersink or print geometry was changed based on
these unconfirmed commercial candidates. The required next evidence is OEM
thread/head/tip identification or supplier confirmation, then seat/envelope and
full-form checks using that exact product and its tolerances.
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

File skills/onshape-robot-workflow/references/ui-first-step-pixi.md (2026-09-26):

# UI-first robot validation and local STEP conversion

Observed on 2026-09-26 using a public Onshape Free document, headless Playwright CLI, D405 camera and closed-loop parallel gripper. Recheck current UI names and package availability for a new task. Case values below are evidence, not universal design limits.

## Scope and API budget

Classify a requested operation as: UI available, UI route not yet verified, UI cumbersome, or UI plus local computation available. Do not call the latter three “API required” without investigation. This study completed all Onshape operations with zero direct REST calls. Do not replace REST with `page.evaluate(fetch(...))` against internal endpoints.

The tested official Free API policy listed 2,500 API calls per user per year and excluded normal browser calls. Check the current official limits before advising a future user. A local helper counter is not the account-wide annual usage; retain its starting value and report only the measured delta.

Cache immutable STEP files by source document/version/hash, plus joint settings, parsed placements and screenshots. Browser HTTP cache and authentication state are separate. Do not publish profile/state/cookies. Do not apply a cached result to changed geometry.

## Reliable browser operations

Use an existing authorized signed-in session or a dedicated headless persistent profile. Verify actual WebGL geometry, title, version and instance count. A successful launch, DOM tree or Loading screenshot alone is not rendering evidence.

Serialize all mutations to a shared page. A yielded command is still running; do not start another edit until it exits. Before selecting parts, verify the trimmed feature-dialog title matches the intended group. After each selection, wait for its exact name to appear; after confirmation, reopen/read the stored state.

Use a fresh DOM snapshot and role/name/parent context rather than old element IDs. The `.os-td` cell can receive editing events where the underlying nonediting input is covered. Discover row data IDs in the current document. Do not send name changes and angle changes without waiting for the previous value to persist.

## Import updates and hidden membership errors

Copy workspace → Create public document can preserve a useful mate structure while producing an independent improvement study. This is a copy/update workflow, not a rebuild from zero. Keep the source unchanged and state the distinction.

Part Studio → Import feature context menu → Update accepts a replacement STEP. Confirm translation and inspect all downstream composites. In the observed update, moved camera bodies became unassigned and required explicit reselection. Final Parts 0 / Composite parts 12 was necessary but insufficient.

Identical left/right pads silently exchanged group ownership. Neutral geometry still looked correct. At the open pose, within-group member placement differed by 32.908 mm. Repair both jaw composites by removing the old union token and selecting their exact 12 part names. Repairing one side temporarily caused overlap with the old other-side union. Recheck both sides and all poses before success.

Never derive an entire rigid group's pose from only one representative until every member has been shown to share it. Save wrong exports as negative controls rather than overwriting the evidence. Names may repeat within a group; preserve occurrence count and index, not a name-keyed dictionary that merges duplicates.

## Native poses and validation

Named positions → Add named position → Driving mate selector → enable Z rotation on all five active mates. Enter zero for axes that must stay still, then apply through the row's name-cell context menu. Capture actual state with Update named position and compare all axes.

Shoulder 10° failed as one jump but succeeded via 1° increments. A wrist limit could be reached using Apply limit position → Max Z angle limit, but the solver moved the gripper to -19.022°. Reset the other axis to zero, apply again and recapture. A missing Apply entry can mean the row already equals the current pose. Solver failure and menu absence are different observations.

Mate context Animate reached the requested endpoint but restored the initial pose on close. Save endpoint poses separately. Slow headless animation can continue after a command yield; check Current value, not just elapsed timeout.

Interference detection: select all intended instances and record the exact scope. Inspect each highlighted result. In the study, six inter-instance overlaps corresponded to screw engagement. Rounded bounding-box dimensions were not overlap volume. Closed composites can conceal internal part intersections; inspect source bodies locally too. Neither one pose nor finite samples prove continuous whole-arm clearance.

## Version and UI exports

Create version only after restoring the intended baseline. Wait until version name, model and URL are stable, then capture the final screenshot. A loading screenshot is not an acceptable final image.

Assembly tab context → Export → STEP, AP242, custom units Millimeter, preprocessing None, Y-up off, individual-parts export off, include hidden instances as required by the declared inventory. Record these settings and inspect units, solids/sheets, names and placements after download.

Important observed pitfall: applying a named pose while viewing a read-only Version changed the display, but STEP export still contained its saved neutral pose. Two STEP DATA sections were identical. Return to Main, apply neutral then target pose, and export each pose there. Separately export the immutable final Version's neutral STEP. Confirm actual movement from the file, not the notification or screenshot alone.

The tested Free UI also offered URDF with STL/GLTF/GLB/OBJ. A reference STL URDF ZIP had 19 links, 18 joints, 261 visuals for 262 bodies, no collision elements and unresolved loop artifacts. Do not claim all native URDF exports have those issues; inspect the current model's output. Keep a reference export distinct from a separately validated converter result.

## Pixi and current OCCT

For `yuki-inaho/urdf_from_step`, the tested `codex/pixi-occt8` implementation locks Python 3.12, pythonocc-core 8.0.1 and OCCT 8.0.1 on linux-64. Official stable OCCT V8.0.1 commit was `b8f597c677811d1f9f4d8a97f5ae2825c0353a42`. Conda-forge supplies the compiled kernel; `pixi run build` builds the converter wheel, not OCCT source. Verify current official stable and actual package metadata for future work; search snippets can lag.

From the converter checkout: `pixi install --locked`, `pixi run versions`, `pixi run test`, `pixi run build`. Use `pixi run convert model.step --config config.json --output new-empty-directory`. The manifest option alone does not change the caller's working directory for arbitrary relative command paths. Check loaded `libTKernel` and test the installed wheel outside the source PYTHONPATH too.

Explicit config supplies joint semantics, occurrence membership, frames and limits; a STEP alone does not reliably provide them. Normalize STEP units to mm once, then mesh/URDF to m. Keep repeated names and same-position occurrences. Validate proper rotation matrices, one rooted tree, finite unit axes, explicit limits and exactly one assignment per nonmetadata body. Test mm/inch, nested placements, repeated bodies and multiple solids with real small STEP fixtures.

OCCT 8 SWIG color lookup required the class form `XCAFDoc_ColorTool.GetColor(label, type, color)` in the tested binding. Instance dispatch selected the wrong overload. Keep the failing regression and rerun after correction. A version pin without execution is not compatibility evidence.

Closed loops need cut frames and external nonlinear coupling, not an invented linear mimic. Compare closure over the agreed sample set, and compare FK against actual UI STEP poses with separately unit-labelled translation and rotation errors. In this study 441 states and 11 poses passed; these counts/tolerances are project-specific. Include reversed-axis, wrong-scale and actual membership-error controls. A zero translation multiplied by 1000 is not a valid unit-error control; assert the fixture perturbation is nonzero.

Missing inertia, zero effort/velocity placeholders, surface-only collision meshes and uncalibrated camera optical frames remain explicit limitations. Numerical FK agreement does not establish physical precision, strength, fatigue, friction, dynamics or ROS launch compatibility.

## Deliverable and skill checks

Document the benefit and its cost: the 30°/+20 mm candidate lowered the camera by 12.40 mm, but increased the compared 250 g moment by 9.45% and lost 18° total wrist travel. A shorter holder does not necessarily reduce the whole system's moment.

Human manuals should label actual screenshots, show precise menu/field sequences, and distinguish old diagnostics from the current accepted version. Check image readiness, print overflow, links, PDF page count and a rendered sample.

When the user asks to commit skills, save SKILL.md and every referenced file under repository `skills/`, not only in the machine's global skill directory or a study archive. Preserve source/provenance and verify all paths are tracked, hashes match, and remote HEAD includes them. Keep unrelated preexisting skills and user changes intact.

Official references:
- https://cad.onshape.com/help/Content/Document/document_menu.htm
- https://cad.onshape.com/help/Content/Document/working_with_imported_cad.htm
- https://cad.onshape.com/help/Content/Assembly/named_positions.htm
- https://cad.onshape.com/help/Content/Assembly/mates.htm
- https://cad.onshape.com/help/Content/File/exporting_files.htm
- https://onshape-public.github.io/docs/auth/limits/
- https://github.com/Open-Cascade-SAS/OCCT/releases/tag/V8.0.1
- https://github.com/yuki-inaho/urdf_from_step

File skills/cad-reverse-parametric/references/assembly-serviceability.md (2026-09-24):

# Assembly and serviceability evidence

Read this for fastening, assembly order, tool access or wiring around a moving
assembly. Keep project dimensions, part IDs and hardware-specific limits in the
study's configuration and report, not in this reusable procedure.

## Fastener record

For every modified joint, record the occurrence path and mating components,
fastener standard/part number, thread diameter and pitch, head/drive geometry,
washer/spacer stack, receiving thread, insertion side, tool, counter-holding
method, and assembly stage. Give every value a source and a status: measured,
supplier-specified, CAD-derived, assumed or unknown. Inventory unreviewed joints
explicitly; a check on one added bolt is not a whole-assembly fastening approval.

A smooth cylinder or a part name containing `M3` is not proof of a usable thread.
STEP leaf count is not screw quantity: one physical fastener can have multiple
solid/surface leaves. Supplier motor-internal screws are not automatically the
external bracket's fastening BOM.

Derive penetration from actual seating and thread-entry planes, including any
recess below the mounting face. Check minimum usable thread engagement and
maximum insertion/bottom clearance independently. Do not count chamfers,
unthreaded relief or a smooth CAD bore as fully engaged thread. Tightening torque
requires the real screw/receiver/material specification; do not infer it from
diameter or from an unthreaded visualization model.
Keep unknown lead-in, neck runout and receiver relief lengths distinct from
explicit zero. Intersect the full-form axial intervals on both parts; do not
simply subtract every relief from nominal penetration, because some exclusions
overlap. Reject nonfinite dimensions before comparisons. A screw size listed
by a supplier does not establish the receiver's compatible thread-forming type.

Changing a flange's diameter or replacing it with a small compression tube can
change its seating face. Intersect the actual trimmed planar faces to measure
contact area; a bounding-box extreme or the old flange datum is not sufficient.
Record partial contact separately from full contact and bearing-stress approval.
For conical or planar seats, common surface area alone does not prove mating:
check that outward material normals oppose at a shared contact point. Two
overlapping male shapes can share a face while penetrating on the same side.
Include that negative fixture before accepting a seat classifier.
A metal compression path may avoid clamping a printed guide, but does not by
itself establish the receiver's strength, retained clearance or axial support.

## Separate final fit from assembly motion

Distinguish placement errors from envelope or seating errors before cutting a
link. Recover the actual output/idler axis from identified cylindrical faces,
cross-check it against the mating part, and measure seat planes separately.
An assembly-node origin is not automatically a functional mounting datum.
Collinear rotation axes still allow axial seat, bolt-pattern and case-width
mismatches.

For each mating face, compare the complete fastener pattern bijectively in the
same physical coordinate frame, then check the actual opposing seat planes and
their trimmed contact area. Do not independently recenter both hole patterns:
that would erase a real assembly offset. Bind the result to the source occurrence
and record which physical part supplied each seat. A geometry-only pass must
leave receiving threads, tolerances, preload, tool access and strength unresolved
until those have their own evidence. Do not enlarge holes merely to absorb a
pattern error; record any authorized diameter change as a separate local feature
decision tied to the selected fastener and preservation mask.

When changing a link length, identify which end stays fixed and which dependent
subassemblies move. Do not apply a downstream translation to the motor anchoring
the fixed end. Derive a regression oracle from the independently placed baseline
components, not from the same hand-written transform list as the generator.
Check both geometry identity and each occurrence's placement; a preserved shape
in the wrong coordinate frame is not a preserved assembly interface.

1. Check the complete saved assembly, with actual occurrence transforms and all
   retained neighbours. Recheck after motor substitutions; baseline approvals
   do not transfer to a larger motor or relocated connector.
2. Define staged insertion and removal paths for parts, washers and fasteners.
   A collision-free seated part may be captive or impossible to insert.
   Installing the first captive part does not prove that the next motor/link can
   enter. Splitting a part does not prove that both resulting pieces can enter.
   Evaluate the entire dependency chain, using every already-installed component
   as an obstacle and checking the final inventory against the declared scope.
3. Check drive engagement, straight approach, turning motion and withdrawal.
   An L-key, screwdriver, bit holder and ratchet have different swept volumes.
   Include holder/handle and a declared finger clearance, not only the bit tip.
4. Check access again after cables and strain-relief hardware are present.
   If another part must be absent, record that assembly precedence and the
   required disassembly for later service. Check a second tool for a held nut.
5. Check what tightening actually clamps. A shoulder/spacer intended to leave a
   joint free must remain proud after tolerances, compression and washer bending;
   nominal positive play alone does not prove freedom under preload.

For a preloaded nut, insert or spacer, separate three operations: loading it into
its host, keeping it in place while the host is transported/inserted, and engaging
the final fastener. A rigid-cluster path only assumes the second operation.
A shaped pocket can provide anti-rotation without axial retention; a reversible
nominal loading path identifies an escape route in that same assembly state, not
friction or gravity behaviour. Do not infer a press fit from a nominal cavity.
If temporary tape, adhesive or a fixture is selected, check added thickness,
thread contamination, removal access and the stage at which it can be released.

Before adding repeated in-situ fastener exchanges or a retention fixture, compare
a bench-preassembly order where the obstructed interfaces are still exposed.
Check the complete subassembly's insertion and access to its **last** mounting
fasteners, not just convenient intermediate steps. Keep final retainers installed
when testing that alternative. A fastened linkage is still articulated: identify
which relative poses need support during handling, and count any separate spacer
as a held loose part rather than assuming it became captive. Choose between
orders using the remaining handling and service constraints, not PASS counts;
retain the original sequence's evidence until the replacement is fully supported.

For bonded pads or liners, distinguish sheet thickness from total cured thickness
including the bond layer. A path that slides a sticky face along its host may not
be a usable bonding operation. Check the actual approach, release-liner handling
and pressure-tool access separately from final contact and bond strength.

Use explicit local head/seat axes transformed to assembly space. For a straight
driver, a circumscribed circular shaft plus a cylindrical handle/hand envelope
can conservatively cover axial insertion and full rotation. Expand by the
declared clearance margin. Such a cylinder is not a model of L-key rotation or
unrestricted human access. Distinguish a sampled path from a continuous swept
volume; report sample spacing and do not call samples exhaustive.

For fixed-section extrusions translated along their extrusion axis, extending
each axial interval by the translation distance gives an exact swept set; sweep
distributes over a union of such constituents. Bind that construction to the
actual nominal part and supported path. Do not reuse it for another direction,
rotation or arbitrary imported shape. Test an obstacle between sample positions
to distinguish sampled clearance from continuous evidence.

Treat supplier assemblies as supplied units only when their boundaries are
known. Multiple solids in one imported node do not identify removable subparts.
If a new support removes a thrust face or changes retention, document the lost
function and its replacement load path, even if insertion and hole sizes pass.

Exclude only the precisely identified intentional mating volume or the specific
not-yet-installed component at a documented stage. Excluding an entire motor,
link or all adjacent fasteners can hide a real access failure. Report contact,
interference and clearance separately, with units and tolerances.

## Cable and connector gates

- Locate the actual header occurrence, outward insertion axis and mating-plug
  exit plane. A cable beginning at a PCB origin can falsely run inside a case.
  Include plug housing, boot and unplugging/grasping space before accepting fit.
- Read the supplier's cable assembly sequence before projecting the PCB header
  axis through the closed case. A removable cover, lateral outlet or hollow
  shaft may change both the required stage and the wire path. A blocked invented
  straight path is not a reason to cut the host. Retain the cover in the final
  inventory, and validate the actual outlet against host material independently.
- Use measured harness dimensions and a manufacturer bend limit when available.
  A round envelope around a flat bundle is conservative, not exact cable CAD.
  Record envelope collisions without silently shrinking it or ignoring cases.
- Use controlled tangent lines/arcs or check curvature on the whole chosen path.
  Free splines can overshoot control points and form tiny bends. Reject legs
  too short for the required radius instead of silently reducing it.
- Check cable-to-cable intersections within each candidate harness, not only
  cable-to-rigid-part intersections. Turning parallel leads toward their own
  terminal-row direction can make their outlet legs coincide. A real fan-out
  needs its own geometry, bend limits and occupied-space validation; do not
  merge overlapping wires into a single accepted bundle.
- Separate post-assembly connector access, preconnected plug fit, final wire
  egress, and insertion of the prewired subassembly. Failure of a straight
  plug-access corridor does not prove every prewiring sequence impossible;
  conversely, preconnecting does not prove the wires are unpinched afterward.
  Tie fixed world-space port planes to explicit pose guards or derive them
  from the current occurrence transform. Reject stale placement assumptions.
- Reserve service loops and strain relief on each side of a moving joint.
  Check pinching, torsion, tension and external obstacles throughout the stated
  motion range. Static path length is not a finished cable cut length.
- Keep electrical evidence separate: pinout, supply range, branch current,
  connector/contact rating, voltage drop, protection and return path. Same
  voltage does not prove that one daisy-chain can carry summed motor current.
  Multiple injection points are not a complete power-distribution design.

## Regression and reporting

Add negative cases before accepting the checker: an obstacle on the shaft path,
an obstruction touching only the handle, a cable blocking an otherwise accessible
bolt, an overlong screw and an insufficient bend radius. Keep the thresholds
unchanged between deliberately failing and passing fixtures. Distinguish a
missing-function RED from a physical negative case tested by the finished code.

Bind reports to input STEP/configuration hashes and record geometry inventory,
units, source transforms, exclusions and stage. A valid export or a successful
browser load is not engineering approval. Show diagnostics in a separately named
unaccepted artifact, preserve the user's existing browser tabs, inspect screenshots
and DOM ownership, and keep release blocked for failed or unknown prerequisites.
Independent binary gates help prevent a local tool-clearance pass from concealing
unresolved assembly, thread, wiring, load or motion failures.
Report unsupported paths and unplanned occurrences explicitly. An unchanged
occurrence count can hide a replacement or omission; compare identities and
preserved geometry, not counts alone.

For round retainers assigned different animation groups, distinguish material
motion from CAD orientation. A washer translated with a pivot can occupy the
same material set as one rotating with its host only after the **complete**
washer is verified as an annulus and both centre trajectories agree. A circular
outer face alone is insufficient: a notch, tab or eccentric bore breaks that
symmetry. Check whole-body exclusion outside intended seating and opposed seat
normals before classifying nominal contact. Keep numerical equivalence tolerances
explicit, and never relabel zero-distance contact as positive clearance.

A deliberate bad fixture is successfully rejected only when the intended
geometric condition fails. An operand-control or kernel ERROR is inconclusive,
not evidence that the detector caught penetration. Test this distinction by
injecting an evaluation error as well as a physically displaced fixture.

For a placement repair, compare complete before/after collision pair identities:
removed, retained and newly introduced. A lower count can conceal a new connector
collision or greater penetration at a retained pair. Bind each scan to its own
exported STEP hash and keep old assembly/tool/cable reports scoped to their old
revision until rerun. Round-trip bounding boxes, areas, volumes and face-family
counts are useful checks but are not a complete arbitrary-shape equivalence proof.

Keep the fabrication/purchasing inventory bound to the reviewed assembly revision.
Reconcile every in-scope saved occurrence exactly once, reject missing/duplicate
entries and quantity mismatches, and list excluded upstream/subassembly scope.
A CAD display partition is not automatically a separate purchased part: any
many-occurrence-to-one-item mapping needs an explicit named representation contract.
Conversely, do not combine same-thread/same-length screws when head, lead, recess
or seating requirements differ. Inventory agreement does not establish dimensional
fit or approve procurement; preserve unknown cables, tools and supplier variants.

## Imported mechanism integration controls

- A node named after an old tool may also carry the next actuator. Before replacing
  it, identify its support, retention and interface functions. Deleting the entire
  node to remove a finger can silently remove the load path. Keep incompatible
  geometry in an explicitly unaccepted diagnostic assembly until a local change
  mask and preserved interfaces have been checked.
- Validate Boolean operands at the placement actually used, not just in their
  original frame: self-difference should be empty and self-intersection should
  retain the original volume. Topology validity alone is insufficient. Report
  failed controls as ERROR, not zero interference. Record absolute tolerances,
  kernel versions and a minimal untransformed/transformed comparison before
  attempting an explicit repair or a different geometry kernel.
- An explicitly recorded common rigid coordinate change can diagnose numerical
  Boolean failures without changing relative placement. Apply the same transform
  to every operand, retain raw results, and rerun operand controls plus deliberate
  penetrating fixtures in each saved pose. Never independently recenter parts or
  promote an ERROR because another frame or an in-memory prototype passed. STEP
  export/reimport can change numerical behavior; test the actual saved artifact.
  Scope supplemental clearance to the exact pairs and poses with working controls.
- Analytic joint trajectories evaluated with forward kinematics are not force
  simulation. State contact, gravity, inertia and joint assumptions. Measure
  closure residuals from the instantiated scene, inject a wrong joint position,
  and verify fixed sensors remain fixed when the downstream joint moves.
- A virtual camera-position scan is not a mount design. Label assumed optics,
  measure occlusion, keep the displaced sensor separate from unchanged physical
  hardware, and recheck the actual relocated housing, support, tools and cables
  before accepting a candidate. Disable multisample blending for integer-ID
  segmentation rather than accepting corrupted object IDs as visibility data.

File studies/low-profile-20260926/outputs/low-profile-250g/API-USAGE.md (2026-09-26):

# Playwright優先・API使用記録

ユーザー追加指示: Onshapeはできるだけ通常UIをPlaywrightで操作し、API limitを節約する。2026-09-26 17:23 JSTから本方針を適用。

2026-09-26追加明確化: **直接APIゼロが第一目標**。下表のAPI例外は自動的な利用許可や必要性の結論ではない。UI機能なし、UI方法未確認、操作煩雑、UI+ローカル処理で代替可の4分類で確認する。既存exporterを使うだけの理由ではAPIへ移行しない。

## 開始状態

- 直接RESTクライアント `work/onshape_api.py` のカウンタ `work/api-count.txt` は **526**。これはこの作業場でそのクライアントを使った試行数であり、アカウント全体の年次使用数ではない。過去のexporter等、別経路は含まない。カウンタをリセットしない。
- 今回の低配置研究から本記録作成まで直接REST呼び出し **0**。ローカルCAD/VTK探索はOnshapeへ通信しない。
- Playwright named session `onshape-headless` を再利用。専用configは `work/cache/onshape/headless.config.json`、Chrome headless=true、1600×1000。profile `work/cache/onshape/profile`、認証state `work/cache/onshape/private/` は秘密情報として成果物/Gitから除外。
- tab0は既存Compact D405 Motion and URDF、tab1はローカル日本語マニュアル。既存Onshape版/別ブラウザセッションを保持する。現在のambient in-app signin表示と、この専用ログイン状態は別。
- 既存のschema・joint定義・版情報は `work/optimization/motion/` などにキャッシュ済み。新ドキュメントのIDを旧IDで代用しない。

## 限度の根拠

[Onshape公式API Limits](https://onshape-public.github.io/docs/auth/limits/)を2026-09-26に確認。Freeは年2,500 calls/user。API keyによる2xx/3xx呼び出しが算入され、通常のOnshapeブラウザからの呼び出しは年次API枠へ算入されない。エンドポイントごとのレート制限は別。ローカルカウンタ526を「年次残り1,974」と解釈しない。正確な年次使用数はMy Account > DeveloperでUI確認する。

## 操作規約

DOM取得→役割/名前/親領域で対象を一意に確認→通常UI操作→成功表示/部品数/関節名を照合→保存/再表示で確認、の順とする。古いe番号を再利用しない。クリックできたことだけで成功判定しない。画像はユーザー向け手順の証拠に利用する。

直接APIの代わりにpage.evaluate(fetch(...))等で内部エンドポイントを呼び出す方法は採用しない。UI操作に伴う通信と、RESTを直接呼ぶスクリプトを区別する。APIが必要な例外は下表に根拠と件数を記録し、同じversionへの読取りをキャッシュする。

## 実行記録

## UI操作経路と例外条件

|処理|第一選択の通常UI経路|成功確認|直接APIの例外条件|
|---|---|---|---|
|新public文書|Documents > Create > Document|文書名/URL/public設定|UIの再取得と限定再試行でも不可能な障害を記録した場合のみ|
|STEP取込|タブ追加メニュー > Import > ローカルファイル選択|翻訳完了、Part Studioの部品/面数|同上。処理中のAPI pollはしない|
|剛体群|Part StudioのComposite part、名前を確認して選択|12群に全ボディが一度ずつ含まれる|必要ならUIからFeature Studioへ再現可能なCADコードを入力する。内部REST直接呼出しはしない|
|Assembly/mate|タブ追加 > Assembly > Insert、Mate connector/Fastened/Revolute等の通常ダイアログ|固定基部、13mateの状態、関節名/軸/リミット|UI経路を試した結果と必要処理を記録して限定利用|
|角度/干渉|Mate編集/Animate、Analysis > Interference detection、Measure|実表示角、閉路、対象選択範囲、干渉結果|正確なpose行列がUIから取得できない場合の少数の読取だけ。中間姿勢はUIで動かす|
|Version|Versions and history > Create version|固有版名、version URL、保存状態|原則不要|
|URDF|最終版からUIでSTEP/STLを出力しローカルでURDFを構築する方法を先に検証|最終版一致、12新STL、関節/pose照合|UI+ローカルの代替経路を検証した後、なお取得できないデータがある場合に限り、必要endpointと最少件数を明記する|

APIを使う前にキャッシュの入力version/config一致を確認する。exporterのキャッシュは別文書/別版へ流用しない。必要な例外の際は、直接呼出しを記録するフックを付けて集計する。認証ヘッダ、cookie、secretはログに記録しない。

## 「画面から実行できない」の判定台帳

|処理|現時点の分類|APIを使わない代替|確定に必要な確認|
|CAD作成/取込/mate/干渉/角度/version|通常UIの機能あり|Playwrightで各ダイアログ操作|今回の画面で成功と保存を確認|
|直接URDF形式で保存|標準UIに機能あり。Free画面から実ZIP取得済み|Assemblyタブ > Export > URDF。指定のSTEP→Pixi変換も実行する|19links/18joints/261visuals。PG3_horn_bolt_1参照欠落、collision要素0、閉路/dynamics未検証。比較用として保持|
|native assemblyの正確な全part変換取得|UI+ローカルSTEP解析で取得可能。11姿勢の262部品を解析済み|各姿勢をMainで適用しUI STEP保存、XCAF配置解析|左右パッドの逆所属をUI修復し全11件を再出力。132剛体行列の内部差0、URDF FK照合PASS。versionの一時的な表示姿勢はexportへ反映されなかった|
|schema/part ID一覧|今回の作業で必須とは未確定|名前と実体CADで対応し、既存schemaを再利用|内部ID取得を目的化しない|
|API年次残量|My Account > DeveloperにUIあり|画面の数値を読む|ローカルカウンタとは別の値であることを記録|

現時点で「直接APIでしか実施できない」と確定した項目は **なし**。代替を試す前に例外件数を計上しない。

2026-09-26の再調査: [公式Exporting Files](https://cad.onshape.com/help/Content/File/exporting_files.htm)はAssemblyのURDF出力を記載しており、実際のFree/public文書のExportダイアログでもURDFを選択できた（`images/onshape-urdf-ui-option.png`）。標準UIの形式がないという前提は採用しない。STL/GLTF/GLB/OBJのGeometry formatと解像度を選べる。直接APIなしでの標準URDFも比較用に取得し、ユーザー指定のurdf_from_step整備を省略しない。

構築経路の確認: [公式Document Menu](https://cad.onshape.com/help/Content/Document/document_menu.htm)のCopy workspaceは別文書へ独立コピーを作成する。[公式Imported CAD](https://cad.onshape.com/help/Content/Document/working_with_imported_cad.htm)のImport feature > Updateは取込元の変更をPart Studioへ反映する。これをUIから実行し、12剛体/mateを再検証する。公式は取込Assembly自体のUpdate未対応も明記しているため、既存の独自native assemblyへ部品更新が伝わることを実表示と出力で検証する。参照切れをAPIで隠さない。

ユーザー指定により、最終URDF経路は **Onshape UI STEP export → yuki-inaho/urdf_from_step（Pixi、最新安定OCCT）→ ローカル検証** とする。標準UIにURDF項目がなくても直接APIを必要としない方針。変換器の整備を後半手順6とDoD D7へ追加済み。

## 実行記録（追記）

|段階|経路|直接API件数|結果|
|---|---|---:|---|
|追加指示までの低配置研究|ローカルCAD/VTK|0|探索継続中|
|開始状態確認|Playwright tab-list、config/counterのローカル読取り|0|既存専用headlessを確認|
|復帰テスト|Playwrightでalert内reconnectリンクをクリック|0|timeout表示消失、base_link一意、12instance/13mateのCAD画面維持|
|独立コピー|Document menu > Copy workspace > Create public document|0|29e8557c76e89bcf64f50566を作成。旧文書を保持|
|STEP更新|Part Studio > Import 1右クリック > Update > ファイル選択|0|新STEPのimport完了通知。カメラ11部品の所属外れを通常UIで修復。未所属Parts 0、Composite 12|
|関節修正|Part Studioのcamera connector編集、Assemblyのwrist Limits編集|0|camera Y165/Z235mm、wrist [-102,124]degを保存後の再読取で確認|
|姿勢/動作確認|Named positionsの5駆動列、mate context Animate|0|11姿勢適用、肩0→10と手首0→124のAnimate終点確認|
|版保存/中立STEP|Create version、Assembly Export AP242/mm/None|0|V1 4577cc931e9bc290e2b31032。262parts/207solid/55sheet、部品名/配置保持|
|標準URDF|Assembly Export URDF/STL Binary/Fine|0|ZIP実取得。比較用、内容の制約はEXPORT.md|
|姿勢STEPと所属診断|MainでNamed positions適用→Assembly Export|0|11件取得。能動軸最大誤差3.058e-6deg、ただし左右padの逆所属を部品行列で検出。V1証拠を保持し修復後に再出力|

更新時の注意: 取込成功の通知だけでは下流のcompositeが全ボディを含むとは限らない。今回、保持形状の対応は残ったが、大きく移動したカメラ部品は未所属になった。Parts欄の残存数と各グループの内容を確認する必要がある。

さらにParts 0 / Composite 12だけでも十分ではなかった。形が同じ左右パッドの旧参照が逆側へ対応し、中立では見分けられないまま、開閉時に逆のjawへ追従していた。UI STEP内の全構成部品の行列を比較して発見した。旧union選択を解除し、左右それぞれ12部品を名前で選び直して修復する。左側だけを直す途中には右側旧unionの重複エラーが現れるので、両方を完了し再出力するまで成功扱いにしない。

自動操作の失敗記録: 非同期run-codeの完了前に次の編集を開いた結果、後続クリックが別グループの選択へ混在した。復旧は通常UIの選択解除・再選択で行う。以後、ブラウザを変更するコマンドは前のexec sessionが終了するまで開始しない。各クリック前に `.ns-dialog-title` のtrimした文字列が目的の編集名と一致することを確認し、クリック後に選択項目が現れたことを待つ。正規表現でdialog全体のraw textに完全一致を要求すると周辺空白でtimeoutになるため、タイトル文字列をtrimして検査する。

姿勢指定のUI経路: [公式Named positions](https://cad.onshape.com/help/Content/Assembly/named_positions.htm)に従い、右端Named positions > Add named position > 駆動mateを選択 > Driving mate selectorのZ回転をチェックすると角度列が作れる。5つの能動関節を登録し、表の値を編集して名前セルを右クリック > Apply named positionで全5値を指定する。最初のcaptureでは過去の操作によるyaw=-27.711°が残っていたため、原点を推測せず全5値0の行を作った。

表の入力にはセル全体 `.os-td` のクリック/ダブルクリックを使う。非編集時のinputだけをクリックするとセルの保護レイヤーが遮る。行の `data-id` はDOMからその都度取得し、旧文書のIDを流用しない。名前/角度の保存、適用通知、モデルの動き、STEP実配置の数値検証は別の証拠として扱う。

今回の失敗と復旧: 肩10°の一括適用で `Mates could not be solved` が出た。1°ずつの中間姿勢は全て適用できた。一方、行名の保存直後に角度を編集すると旧角度へ戻る競合も発生したため、各編集・適用後の安定待ちと保存値再読取を追加した。既に現在姿勢と等しい行はcontext menuにApplyが出ない場合がある。メニュー不存在だけでsolver失敗とは判定しない。

AnimateではCurrent valueが終点10°へ到達したが、閉じると0°へ戻った。終点表示を保存姿勢の証拠として流用しない。101 stepsはこのheadless環境では数分かかり、30秒timeout中にも3.465→6.733→10°と進んでいた。時間切れだけで機構不動と判断せず、Current valueの変化とエラー表示を確認した。

姿勢出力の落とし穴: 読取り専用versionでもNamed positionsのApplyは使えるが、今回のSTEP exportは版に保存された中立姿勢を出した。yaw10表示のファイルとzeroはSTEP DATA全体が同一だった。Mainへ戻って適用・出力するとyawの回転行列が得られた。画面の成功/ファイルの存在/実配置を三段階で区別する。

復帰前 `headless-start.png`、復帰後 `headless-reconnected.png` を実画面で確認。最初にメッセージ全体をクリックしても復帰しなかった。DOMからリンク `a.osx-message-bubble-link` を特定し、正確なテキストで一意性を検証してクリックすると復帰した。「クリック成功」と「接続復帰成功」は別の確認が必要。APIカウンタは526のまま。
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

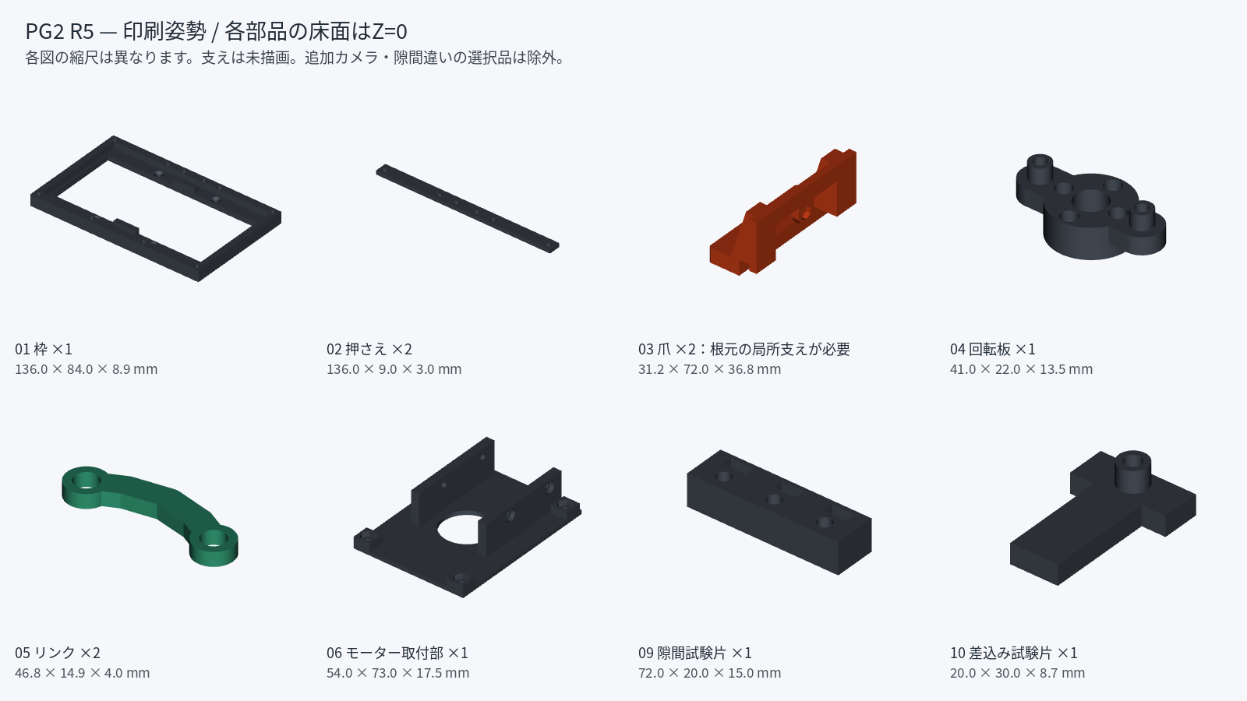
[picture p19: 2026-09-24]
references/pg2-r5/PG2_XL430/images/print_layout.png

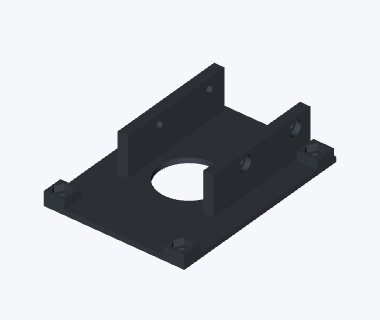
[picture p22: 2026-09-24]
references/pg2-r5/PG2_XL430/images/print_06_motor_mount.png

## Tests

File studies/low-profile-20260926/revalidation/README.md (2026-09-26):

# 継続作業 — 検証器の誤合格防止と実STEP再検証

## 結果と証跡

入力コミット: `bba1f4e0762b35f84ebe8d3cfaaf41180e453831`。
入力ZIPのcommentとGitHub対象ブランチの先頭を照合し、元snapshot 327ファイルのSHA256が全件一致した。
詳細は [input-integrity.json](input-integrity.json)。

|検査|今回の結果|証跡|
|---|---|---|
|旧D6/D7|保存証跡の監査完了。新しいOCCT8実行ではない|[handoff-audit.json](handoff-audit.json)|
|修正前の12負対照|11件が誤受理されテスト失敗、1件は元から拒否|[hardening-red.xml](hardening-red.xml)、[log](hardening-red.log)|
|修正後の全試験|既存4件＋追加48件、52 PASS|[full-tests.xml](full-tests.xml)、[log](full-tests.log)|
|STEP本体の再読込|11×262＝2,882部品姿勢、baseline込み3,144件|[再抽出JSON](step-replay/native-pose-transforms.json)、[log](step-replay.log)|
|閉路441状態|最大3.469446951953614e-17 m、基準1e-6 m|[再読込後の検証](kinematics-step-replayed.json)|
|11姿勢FK|最大8.784880096336909e-9 m / 5.3371044601806986e-8 rad、基準各2e-5|同上|
|実V1不良対照|爪のmemberに5.16416212733822 mmの相対移動、正しく拒否|[failure.json](v1-step-negative/failure.json)、[log](v1-step-negative.log)|

CAD寸法、STEP/STL、URDF、関節設定、元の許容値は変更していない。
小さい数値誤差は同じCAD由来の座標計算が一致したという意味で、実物のナノメートル精度ではない。

## 修正内容

`robot/validate_robot.py` は11件という数だけでなく、定義済みの11姿勢を重複・欠落なく含むことを検査する。
有限値、正しい4×4剛体変換、全12グループの部品数・所属、固定V2と入力SHAを検査する。
URDFのリンク/関節/軸/制限/原点を設定JSONと照合し、visualとcollisionのメッシュ・原点・scaleも検査する。
外部パス、親ディレクトリへの参照、モデル外へのsymlink、不一致ハッシュを拒否する。
`assert` に依存せず、不正データは非ゼロ終了する。

`--model` は検証したい出力ディレクトリ、`--native` はSTEPを独立再読込した姿勢情報。
デフォルトは標準出力のみ。`--output` は未作成ファイルだけに書き、過去の `robot/validation.json` を更新しない。
本検証器は**この固定V2用**であり、任意の新設計を受け入れる汎用ロボット検証器ではない。

`robot/replay_step.py` は付属 `scripts/assembly_io.py` のXCAF readerを使い、STEPを直接再読込する。
全構成部品の名前・数・solid/sheet・面数・局所boundsを照合し、同名部品の繰返しも保持する。
代表部品だけでなく全memberの剛体運動、5能動関節の角度とpivotを確認する。
各姿勢の全262件を新しいJSONへ保存し、途中失敗は成功として扱わない。
局所bounds/面数の一致は形状同値性や強度の証明ではない。

## 実行環境

今回実測: Python 3.13.5、NumPy 2.3.5、SciPy 1.17.0、trimesh 4.11.1、pytest 9.0.2。
STEP再読込だけに CadQuery 2.8.0、cadquery-ocp 7.9.3.1.1 を使用。
元PCのrtk、Pixi、pythonocc-coreと元R5 STEPは本環境にない。外部シェルDNS取得も失敗した。
固定converter commitとlockはGitHub connectorで読んだが、新しいlocked install/build/convertは未実施。
元の13 converter＋18 CAD試験は過去XMLの監査であり、この52件に合算しない。

今回は既存環境を `uv run --no-project --offline --python python python ...` で明示使用した。
このパスは本環境固有。利用者側では次の `PY` を適切なPythonに設定する。
requirementsは直接依存の版記録で、全推移依存のlockではない。新規環境構築の再現試験も未実施。
既存のroot uv.lock（元CAD環境）は書き換えていない。

## 追試コマンド

展開したリポジトリのルートで実行する。ネットワーク、Onshapeログイン、APIキーは不要。
依存パッケージの事前準備だけは別途必要となる。

新規環境を用意する場合の例は `python3.13 -m venv temp/d405-venv`、
続いて `temp/d405-venv/bin/python -m pip install -r studies/low-profile-20260926/revalidation/requirements-cad.txt`。
これはネットワーク取得を伴う準備例であり、この新規インストール自体は今回未試験。
運動学検査だけならrequirements-kinematics.txtを使用する。

```sh
BASE="$PWD/studies/low-profile-20260926/outputs/low-profile-250g"
PY=python
RUN="$(mktemp -d)"

# 保存モデルを検査。既存validation.jsonは触らない。
"$PY" "$BASE/robot/validate_robot.py" \
  --model "$BASE/robot/model" --output "$RUN/saved-model.json"

# 52件。生成キャッシュは検証成果と区別する。
"$PY" -m pytest -q \
  "$BASE/robot/test_validation.py" \
  "$BASE/robot/test_validation_hardening.py" \
  "$BASE/robot/test_validation_contract.py" \
  "$BASE/robot/test_replay_step.py" \
  --junitxml="$RUN/tests.xml"

# STEP再読込。replayは新規ディレクトリでなければ拒否する。
"$PY" "$BASE/robot/replay_step.py" --output "$RUN/replay"
"$PY" "$BASE/robot/validate_robot.py" \
  --native "$RUN/replay/native-pose-transforms.json" \
  --output "$RUN/fresh-step-model.json"
```

V1不良対照は次のコマンド。**非ゼロ終了が期待値**である。

```sh
"$PY" "$BASE/robot/replay_step.py" \
  --pose-dir "$BASE/CAD/native-poses/diagnostics/v1-pad-misassigned" \
  --output "$RUN/v1-negative"
```

新規再変換先の検査は
`"$PY" "$BASE/robot/validate_robot.py" --model outputs/fresh-robot --output "$RUN/fresh-conversion.json"`。
このコマンド自体は変換ではない。変換器については [CONVERTER.md](../outputs/low-profile-250g/CONVERTER.md)。

## 失敗履歴の読み分け

`hardening-initial-import-error.*` はpytest import modeの選択ミス、
`patch-not-applied-tests.*` はpatch未適用時の失敗、`step-replay-interrupted/` はtool時間制限による途中中断。
いずれも成功回数には含めない。完成した結果は上表のファイルを使う。
`kinematics-hardened.json` は保存JSONを用いた検査、`kinematics-step-replayed.json` はSTEP再抽出後の検査。
元の `robot/validation.json` と過去XMLは履歴として保持する。
物理的FAIL/UNKNOWN、未実施のOCCT8再変換、運用上の注意は [REVIEW.md](REVIEW.md) を参照。

## アーカイブ展開後の追試

[packaging-rehearsal.json](packaging-rehearsal.json) にtar.zstの作成・zstd検査・別配置への展開・
全ファイルSHA256照合を記録した。展開先でも [52試験](relocation-tests.xml) が通り、
11姿勢のSTEPを再読込して [441/11検証](relocation-kinematics.json) を実行した。
再抽出した姿勢JSONは元の再抽出結果とSHA256まで同一だった。
意図的なファイル改変と未登録ファイルの混入も、整合性検査器がそれぞれ非ゼロ終了で検出した。
これは同じ依存環境での別配置試験であり、新規インストール試験ではない。
リハーサル後に作業記録を封入して最終archiveを再生成するため、上記JSONのarchive SHAは
最終提出物のSHAとは異なる。最終提出物は同梱外の `.tar.zst.sha256` で識別する。

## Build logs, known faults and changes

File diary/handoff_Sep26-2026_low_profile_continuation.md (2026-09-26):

# 次の引き継ぎ — 検証器改善・独立STEP再検証

2026-09-26。今回の基点は `bba1f4e0762b35f84ebe8d3cfaaf41180e453831` と同じ入力ZIP。
提出はtar.zst。remote commit/pushとOnshape変更は行っていない。

まず [提出物の入口](../START_HERE_ja.md)、
[継続作業書](workdoc_Sep26-2026_low_profile_continuation.md)、
[追試README](../studies/low-profile-20260926/revalidation/README.md)、
[レビュー](../studies/low-profile-20260926/revalidation/REVIEW.md) を読む。

## 完了したこと

旧D6/D7は保存証跡の監査として一項目ずつ照合・記録した。原本作業書と成果物WORKDOCを同期した。
旧検証器の12負対照中11件の誤受理を修正し、既存4＋追加48＝52テストを実行。
validate_robot.pyは--model/--native/--inputsを受け付け、新規--output以外へ書き込まない。
代表部品だけでなく全memberを検査するreplay_step.pyを追加。
V2の11×262部品姿勢を再読込し、441閉路・11FKを元の基準で合格確認した。
V1はsmall_gripper_drive/jaw_lのmember相対移動5.16416212733822 mmを検出し失敗した。

## 次の実行者が注意すること

最終形状は引き続きV2 `f6162b4adc88af9d07f1194a`。CAD/STL/URDFは今回未変更。
元のPG3非線形閉路はpg3_states.pyで解く。線形mimicへ置き換えない。
新しく変換したモデルは必ず--modelで明示指定する。既存--outputへの上書きは意図的に拒否する。
replay_step.pyを移設するときはrepoのscripts/assembly_io.pyとAGENTS.mdも同じ構造に保つ。
認証情報や元PCのbrowser profileは不要で、この提出にも含めていない。

元のPixi/OCCT8変換環境は今回再現していない。過去のbuild/XMLと独立CadQuery/OCP再検証を混同しない。
本環境はPython3.13.5、NumPy2.3.5、SciPy1.17.0、trimesh4.11.1、pytest9.0.2、
CadQuery2.8.0、cadquery-ocp7.9.3.1.1。requirementsは直接依存記録で完全lockではない。
元R5 STEPとconverter wheel実体は入力ZIP外。元CAD18試験の今回再実行は未実施。

製作承認false、物理的FAIL/UNKNOWNは維持する。
材料・造形方向・荷重条件を定める新作業書と実測を、次の設計改善の前提にする。
今回の作業書を根拠なく機構全体の完成・印刷許可へ読み替えない。

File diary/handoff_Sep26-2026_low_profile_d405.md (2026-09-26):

# 次エージェントへの引き継ぎ — Onshape低配置D405

> 継続作業後の入口はリポジトリ直下の START_HERE_ja.md と diary/handoff_Sep26-2026_low_profile_continuation.md。
> 以下は20:20 JST時点の保存記録。旧D6/D7はその後に証跡監査し、別環境で検証器を改善した。

**引き継ぎ日時: 2026-09-26 20:20 JST。ユーザー指示により実作業をここで止め、保存と引き継ぎへ切り替えた。**

## 最初に読むもの

1. [作業書](../studies/low-profile-20260926/outputs/low-profile-250g/WORKDOC.md) が正本の写し。通常36/36項目完了、DoDはD1〜D5完了、**D6とD7が未チェック**。完成済みと誤認しない。
2. [人向け20ページマニュアル](../studies/low-profile-20260926/outputs/low-profile-250g/MANUAL.pdf) / [HTML](../studies/low-profile-20260926/outputs/low-profile-250g/MANUAL.html)、[比較REPORT](../studies/low-profile-20260926/outputs/low-profile-250g/REPORT.md)。19画像、実メニュー・失敗・修復を記載。
3. [最終レビュー](../studies/low-profile-20260926/outputs/low-profile-250g/final-review.md)、[API-USAGE](../studies/low-profile-20260926/outputs/low-profile-250g/API-USAGE.md)、[CONVERTER](../studies/low-profile-20260926/outputs/low-profile-250g/CONVERTER.md)、[URDF検証](../studies/low-profile-20260926/outputs/low-profile-250g/robot/validation.json)。
4. [スキル案内](../studies/low-profile-20260926/outputs/low-profile-250g/skills/ONSHAPE-WORKFLOW.md)。設計repo直下 `skills/` に4スキル13ソースを参照/agents込みで保存済み。

直近のユーザー追加指示は「skillsをリポジトリskills/へcommit漏れなく」「作業書をdiary/へcommit/push」「続きは別エージェントへ。引き継ぎ文書もcommit/push」。新しい設計や試験を勝手に進めず、現在点を残した。引き継ぎ先へメッセージ送信や新規チャット作成は行っていない。

## 作業場所とGit

|用途|場所 / ブランチ|
|---|---|
|元の作業場|`studies/onshape-20260926`（親自体はGit外）|
|正本workdoc|`work/temp/workdoc_Sep26-2026_low_profile_d405.md`|
|ユーザー成果物|`outputs/low-profile-250g/`|
|今回コード|`work/low-profile/`|
|設計Git checkout|`work/gripper-low-profile`、`codex/onshape-low-profile-d405`|
|設計保存コピー|repo内 `studies/low-profile-20260926/`|
|変換器Git checkout|`work/urdf_from_step`、`codex/pixi-occt8`|
|作業書/レビュー/引き継ぎ|設計repo内 `diary/*Sep26-2026_low_profile_d405.md`|

設計originは `https://github.com/yuki-inaho/3d-printed-dynamixel-gripper.git`。途中保存 `6117edb`、**最終実体成果物 `00bd70c4e995788298d98e9de78f0e5e6d70ca35`** をpush済み。引き継ぎ記録はその後続commitへ保存する。変換器originは `https://github.com/yuki-inaho/urdf_from_step.git`、**`1b2cea31c56b875bf98c1d65084781322f5fc835`** をpush済み。両remote SHAをls-remoteで確認した。PR作成・mainへのmergeはしていない。

元repo `.` は変更していない。`../low_cost_robot` には本作業と無関係な未追跡4ファイルがある。HN11アイドラのintent/parts/validate/testで、削除・commit・修正していない。今後も他作業として保持する。

全shellコマンドは `rtk` を先頭に付ける（`RTK.md (local instruction)`）。ユーザーはFree/public、headless、直接Onshape API最小化、250g payloadを指定。材料・造形方向は未指定。印刷、通電、購入は行っていない。

## 再開順序

1. `start-work-with-docs` に従い正本と現在の未チェック項目を確認し、`date "+%Y-%m-%d %H:%M:%S %Z%z"` で開始を記録する。引き継ぎ時点でactive-itemはなし。残りをまとめてチェックしない。
2. **D6**: `API-USAGE.md` の操作一覧・例外なし・直接API0・旧ローカルcounter526不変・キャッシュ利用を証跡と照合する。本文と証拠は既に揃うが、最終DoDチェックは未実施。
3. **D7**: Pixi lock、公式OCCT8.0.1根拠、実ロードkernel、wheel、13小STEP試験、V2実変換、441/11照合、保存commitを照合する。実装/実行は完了し、最後のDoD照合だけ未実施。
4. 各チェック直後にlog_work.pyで記録し、必要なレビュー追記を行う。成果物・`skills/`・`diary/` の内容を同期し、限定pathspecでcommit/pushする。今回の引き継ぎ保存を全DoD達成とは扱わない。
5. その後に新しい設計改善をするなら、材料・実物荷重/トルク/摩擦等の前提を新作業書へ分離する。既存のUNKNOWN/FAILを理由なくPASSへ変えない。

## 現在のOnshape

推薦する比較版は [V2 Low profile D405 - corrected jaw pads](https://cad.onshape.com/documents/29e8557c76e89bcf64f50566/v/f6162b4adc88af9d07f1194a/e/d5415bf725ba822741b01703)。

- Document `29e8557c76e89bcf64f50566`、workspace `6bce790334ee57d808213530`。
- Part Studio `2195f3c400eb079287ae06af`、Motion Assembly `d5415bf725ba822741b01703`。
- V2 `f6162b4adc88af9d07f1194a`。12 composites、12 instances、13 mates、baseだけ固定。
- V1 `4577cc931e9bc290e2b31032` は左右pad誤所属の失敗版。最終として使わない。
- 以前の75°compact文書は `7b85d8922959cbe564b6e0cb`、別文書として保持。

今回のV2は旧compactのCopy workspace＋Import Updateで作った改善版。今回ゼロから再構築したと主張しない。以前の独立再構築と区別する。

## ブラウザとキャッシュ

Playwright CLI session `onshape-headless`、1600×1000、persistent profile。APIキーでの作業はしていない。ambient in-appのsignin画面と専用Chromeのログイン状態は別である。

```sh
cd studies/onshape-20260926/work
rtk proxy npx --yes @playwright/cli -s=onshape-headless tab-list
```

引き継ぎ時、tab0はV2 read-only Assembly、tab1は旧マニュアル、tab2は今回のマニュアル。CAD上で編集中ダイアログや実行中のAnimateはない。tab2が選択中。Onshape操作前にtab0を選び、DOMと実表示を再確認する。URL/タイトルだけでWebGL描画完了としない。

ローカルpreviewは `http://127.0.0.1:8767/low-profile-250g/MANUAL.html`。serverはoutputsをrootにして起動中だが、セッション継続は保証されない。停止していたら作業場で `rtk proxy python3 -m http.server 8767 --bind 127.0.0.1 --directory outputs` を使う。既存serverがある場合は二重起動しない。

configは `work/cache/onshape/headless.config.json`。profileと `work/cache/onshape/private/` の認証stateは700/600で保護され、Git/成果物へ含めていない。秘密値を表示・commitしない。旧APIクライアントのcounter `work/api-count.txt` は526で、この研究の増分0。年次残量ではない。内部fetchをAPI節約の代用にしない。

## 設計結果と交換条件

採用は `E20_P30_Y165_Z235`。D405俯角30°（+Yから下向き）、ガラス中心(-0.2,165,235)mm、爪+20mm。旧75°に対しカメラ高さ-12.40mm。比較部分の250gモーメントは0.350412→0.383540N·m、**+9.45%**。変わらないアーム/グリッパ重量は比較部分に含めない。

5,040候補、光学356通過、実マウント33候補/31通過。30°で成立する最小延長20mm、その群で最低高さを採用した。より低い25/30mm延長案は負荷増が大きい。大域最適/全体負荷改善/強度改善は主張しない。

爪根元Y<203.6mmを保持し先端だけ延長。非CAM5 236部品中232保持、4爪/pad変更。2爪+2マウントは有効な単一solid、水密STL。両眼3対象で最小可視率0.932768、最短78.685mm。848×480の75mm基準PASS、720p100mmはFAIL。実カメラ校正・反射・深度性能は未検証。

開閉23姿勢×6,100対象ペアの旧新比較で新規/悪化干渉なし。既存8接触/小隙間FAILは保持。手首physical[-124,102]°、native/URDF[-102,124]°で以前より合計18°狭い。サンプル確認であり連続全関節の証明ではない。

12本の段階別工具包絡はPASS。完成状態の台座4本は工具アクセスFAILなので台座→カメラ付きcarrierの順。締結保持、実物公差、ケーブル、材料、疲労/クリープ、連続トルクは不明。製作承認false。

## URDFと実検証

- 最終入力 `CAD/final-version.step`、SHA256 `9f58c947753e9229b30939da23ce4c87c1cc85eeb39372518de4ffb98991b93f`。
- 262 occurrences / 207 solids / 55 sheets。12新STL、16links、15joints（5能動/4受動/6固定）。`robot/model/robot.urdf` が最終。
- `robot/converter-config.json` はUIの軸/位置/limitsと所属を明示。STEPから関節意味を自動推定したものではない。
- `pg3_states.py` で非線形閉路を解く。441状態の最大残差3.46945e-17m、11native姿勢の最大並進8.78488e-9m、回転5.33710e-8rad。基準は閉路1e-6m、pose各2e-5m/rad。
- 小STEP13＋FK負対照4＋CAD18＝**35試験PASS**。実V1 pad誤所属、逆軸、1000倍単位などを拒否。13品質項目PASS、20p/19画像のPDF/HTMLを確認済み。
- inertialなし、effort/velocity=0は未設定。camera_bodyは校正済みoptical frameではない。55 sheetsを含むSTLは物理エンジン用convex/watertight collision保証なし。ROS launch/RVizは未検証。

### 再現コマンド

変換器環境はPixi0.79.0、Python3.12.14、pythonocc/OCCT8.0.1 linux-64。公式V8.0.1 commit `b8f597c677811d1f9f4d8a97f5ae2825c0353a42`。OCCTはconda-forge binaryで、ソースコンパイルしたとは主張しない。

```sh
cd temp/intake_d405_20260926/converter
rtk proxy pixi install --locked
rtk proxy pixi run versions
rtk proxy pixi run test
rtk proxy pixi run lint
rtk proxy pixi run build
rtk proxy pixi run python ../../outputs/low-profile-250g/robot/validate_robot.py
```

再変換はCONVERTER.mdのコマンドで空の出力先を指定する。既存modelを削除して上書きしない。PYTHONPATH空でinstall済みwheelからV2の262部品を読めた証拠も `reports/converter-wheel-intake.json` にある。

CAD側は元gripper repoのuv/CadQuery2.7環境を使う。変換器のOCCT8とは分離している。

```sh
cd studies/onshape-20260926
rtk proxy uv run --project . --no-sync pytest -q work/low-profile/test_design.py work/low-profile/test_validation.py
rtk proxy python3 work/low-profile/log_work.py start '対象項目と完了条件'
# 対象項目だけを検証した後に done を実行する。
rtk proxy python3 work/low-profile/log_work.py done '実結果と証跡'
```

## 再実行してはいけないもの・失敗の教訓

- `archive_v1_poses.py` は実行済み移動操作。現在の正常poseを旧失敗フォルダへ移すので無条件再実行しない。
- `create-repaired-version.js`、全pose exportなどのUI変更スクリプトは記録用。必要な理由と現在stateなしで再実行しない。
- 旧 `work/optimization/motion_pipeline.py` / `work/export_robot.py` はAPI経路。今回の標準経路では使わない。
- V1では同形padの所属が左右逆だった。代表部品だけの行列では検出できない。全memberを照合し、修復後11姿勢全件を再出力済み。
- read-only Versionで一時姿勢をApplyしてもSTEPが中立になる場合がある。MainでApplyしてpose STEPを出す。最終固定版の中立STEPは別に保存する。
- Animateの終点は閉じると戻った。Apply limitでも他軸が動き得る。全5軸を再捕捉して確認する。
- UI更新は逐次実行。非同期処理が終わる前の次操作で別Compositeへ選択が混入したことがある。
- OCCT8色bindingはクラス経由GetColorが必要だった。初回11失敗のXMLを保持。単位負対照も並進0のyawでは無効だったため肩poseへ直した。
- 元repo全体のclean要求は、無関係な未追跡HN11作業を誤ってFAILにした。削除せず範囲外として記録した。

## 保存の注意

`checkpoint.py` は新研究だけを `studies/low-profile-20260926` へコピーしmanifestを作る。認証/profileは対象外。`sync_skills.py` は4スキルだけを同期。`sync_diary.py` は作業書・レビュー・引き継ぎをdiaryへ同期する。通常は限定pathspecを使い、outputsはignoreされるため今回の出力範囲だけ明示して追加する。

設計コードは元repoとworkspace配置に依存する。保存コピーだけで全工程が自動実行できるという意味ではない。別マシンでは配置と依存を明示して準備し、古い文書IDへ書き込まない。

引き継ぎ時点の「未完了」はD6/D7の最終監査と、その後の完了記録。デジタルモデルの実生成・35試験・441/11照合は済んでいる。物理的未知は検証済みへ繰り上げない。

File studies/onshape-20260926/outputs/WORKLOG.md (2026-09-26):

# Onshape取り込み・URDF出力 作業記録

開始: 2026-09-26 JST

## 依頼と範囲

ローカルの low_cost_robot と 3d-printed-dynamixel-gripper を調査し、アーム・グリッパ・カメラマウントをOnshape Freeの公開ドキュメントへ取り込み、URDFを書き出す。実績を元に再利用可能なOnshapeスキルを作る。有料機能・購入なし。

## 入力選定

- low_cost_robot は上流の原型。旧URDFはXL330混在・旧グリッパのため最新候補のURDFとして転用しない。
- 最新統合候補: `./outputs/camera-mount-id5-overhead-d405-r5/CAD/ID5_D405_mid_ASSEMBLY.step`
- 5台のXL430、ID5単独PG3開閉、D405マウント65°。257 named occurrences。実機IDとCAD対応は未確認。
- 資料中の印刷・SD書込・通電などの旧依頼は今回の作業指示ではない。今回行うのはCADの取り込み・関節定義・エクスポート。
- 元リポジトリとSTEPは変更しない。取り込み成功を機械設計や製作の受入とみなさない。

## 参照資料

- Onshape Free: https://www.onshape.com/en/products/free
- Onshape標準形式取り込み: https://www.onshape.com/en/resource-center/tech-tips/import-file-formats-step-parasolid-stl-dxf-dwg-pdf
- 取り込みオプション: https://www.onshape.com/en/resource-center/tech-tips/import-options-use-cases
- onshape-to-robot導入: https://onshape-to-robot.readthedocs.io/en/latest/getting_started.html
- 関節・リンク命名: https://onshape-to-robot.readthedocs.io/en/latest/design.html

## 経過

1. Playwrightのheaded Chrome、named session `onshape` をユーザーがログイン済み。Free表示を確認。
2. CLIのDISPLAY未設定を `DISPLAY=:1 XAUTHORITY=/run/user/1000/gdm/Xauthority` で解消。既存デスクトップを利用。
3. browser-actスキルは導入済み。CLI 1.4.2を導入しcore手順を取得。現在のログインはPlaywright session内にあるため、そのまま再利用。
4. 原本・改訂履歴を照合し、上記D405 R5統合候補を選定。
5. 公開ドキュメント `1f8f316ef4f488303d1c1902` 作成。29 MB STEPを「Combine to a single Part Studio」、Y-up変換なしで取り込み。257 occurrence → 262ボディ（207ソリッド、55サーフェス）。Importフィーチャの状態OK。
6. 原本取り込みを `V1 imported D405 R5 reference` として保存。Version ID `e8d5c7e201d5f83367145f5a`。
7. 12 closed composite parts に整理。262ボディを重複なく帰属させ、参照用元データはV1とSTEPタブに保持。`link-membership.json` が台帳。
8. 12インスタンス、11ツリー接続＋左右2閉ループ接続を作成。ケース側へカメラを固定。J4に既存干渉診断の暫定範囲 −138〜+110°、PG3クランクに −65〜+45°（機構角25〜135°）を設定。J1〜3の実用範囲は未確認。
9. APIキーは読取・書込のみ。削除・購入・共有権限なし。秘密値はwork内の600権限ファイルにのみ保存、公開成果物へ含めない。Free年間2,500回枠を確認し、タスクの呼び出し回数を計数。

## Findings / Tips（随時追加）

- ローカル部品数とOnshapeボディ数は同じとは限らない。複数ソリッドやシートを含むSTEP occurrenceは展開されるため、名前と体積を対応付ける。
- 単一Part Studio取り込みで大量タブ化を回避できる。可動剛体はClosed Composite Partにまとめるとアセンブリが12インスタンスとなり扱いやすい。
- スキルでCLI `upload` を使う場合、`run-code`内でfile chooserにsetFilesした後にCLI `upload`を重ねると取り込みダイアログが二重になる。二重表示はキャンセルし、1回だけImportを確定。
- 同方向の明示Mate Connectorを組むとき、Mate既定値 `primaryAxisAlignment=true` は第2軸を反転し、リンクが180°反転する。今回はfalseへ修正。接続前後の全occurrence変換行列を照合する。
- 全MateがOKでも姿勢一致とは限らない。APIのoccurrencetransformsだけでは拘束済み姿勢が元に戻らない場合があった。J1のコンテキストメニュー **Reset** で中立へ戻した後、全12リンクの変換行列が原本配置と最大約1e-14で一致。
- 通常のブラウザ認証で公開GETはできても、REST POSTは401となった。公式Developer画面のAPIキーと署名付きAPIに切替。秘密値をログに出さない。
- バージョン作成APIはURL内didだけでなくbodyのdocumentIdも必要だった（欠けると400）。
- API v17はbtType形式、旧デフォルトAPIはtype/typeName/message形式。featureSpecs既定値を変換するとき、`{"type":0}`はnullへ変換しないと抽象BTQueryFilterの400となる。
- 元STEPに材料密度なし。Onshape mass propertiesはhasMass=false。現時点では出力を運動学モデルとして扱い、質量・慣性を実測済みと表示しない。

## 追加依頼

ユーザーより、Onshapeの検証機能を使った改善と使い方への習熟、および別公開プロジェクトで0から同モデルを作成して手順を再検証する依頼。1件目の手順・結果を整理後に独立再実行する。

## 完了条件

- [x] 公開Onshapeドキュメント作成、統合CAD取込と視覚確認
- [x] CAD出典とリンク・関節対応を保存
- [x] URDFと参照メッシュ出力
- [x] URDF構造・単位・参照・描画を確認
- [x] スキルを作成・検証
- [x] URL、成果物、再現方法、制約を記録

## 検証による修正（1件目）

- Native Animateで「Unable to compute any steps ... Instance(s) may be constrained」。13 MateがOKでも機構が動かない状態を検出。
- API制限値の`expression`だけを変えたことが原因。内部`value=0`、`units=""`が残っていた。実験で制限を無効化すると動き、数値・単位も一致させると制限付きで動作。最終実装は角度のdegree、長さのmillimeterも明示。未使用のlimitパラメータは送信しない。
- CADの正軸回転とOnshape matevalue/今回のURDF正方向は逆。機構角thetaに対して gripper_drive=90°−theta。最終範囲は−45〜+65°。J4はCADの暫定−138〜+110°を変換し、URDF/nativeで−110〜+138°。初期記載の範囲は修正前の値。
- 全開theta25°でnative drive=1.134464 rad、左右slider=±0.0164539805 m。全閉theta135°はsolverの境界許容差内で到達。AnimateのCurrent valueが実際に変化することも確認、スクリーンショット保存。
- 12インスタンスを選択したNative Interference detectionでは中間・全開・全閉とも6件。wrist–camera_mount 4件、camera_body–camera_mount 2件。ねじ取付部に対応する候補だが、締結成立・材料強度を認定したものではない。composite内部の交差やアーム全可動域は今回の3姿勢検査の範囲外。
- V2 `9d614fea1354d083cde3bf56` に修正済みモデルを保存。
- onshape-to-robot 1.8.3で12形状リンク、2閉ループの4補助フレームを出力。質量が未定義なので運動学モデル。

## 独立再作成

「0から」は元STEPの再取込→リンク/関節定義→検証→URDFを新しい公開ドキュメントで行う意味として進行。全形状のスケッチ再描画は実施していない。
新規ドキュメント `531556789fcbb8dfdcac2689`。1件目のコピー機能は使わず、同じ入力STEPを新たにアップロード。
学習内容を `$onshape-robot-workflow` として保存・frontmatter検証済み。この手順を使って2件目を組み立てる。

## 独立再作成の結果

- 入力を新規アップロードし、同じ262 bodyから12 composite、26 connector、13 Mateを作成。初回文書のcopyは未使用。
- 作成直後の12 occurrence変換行列は原本配置に一致、最大差0。Mate全13件OK。
- 全開25°、全閉135°、中間90°へ移動。Native AnimateのCurrent value変化も確認。3姿勢のInterference detectionは初回と同じ6件。
- 2件目のVersion `64249f2de6a8cce71fff923f` を保存し、その固定VersionからURDF出力。TranslationがDONEであることを最終確認。
- 初回、再作成とも16link/15joint。12メッシュすべてで双方向最近傍頂点距離0、三角形数一致、表面積差は浮動小数点誤差。10個はSTLバイト列が異なったが、三角形の順序による差だった。単純な辞書順の頂点比較も微小なゼロ符号等で対応がずれるため、最近傍比較へ修正。
- 関節の親子・型、並進、軸、制限は一致。回転行列の要素差は最大約5.31e-6（エクスポータ数値丸め、±π表現）。
- 各URDFを441角度で検証し、最大閉ループ位置残差2.30765e-7 m。Onshape上の閉ループ両点残差は記録した3姿勢で約1e-15 m以下。
- メッシュ参照、木構造、単位、ゼロ姿勢を検証し、URDFから4パネル画像 `urdf-kinematics.png` を生成して視覚確認。
- Freeの公開ドキュメントであることを両方のdocument APIの `public=true` で確認。有料機能・購入なし。Developer画面の記録時点ではAPI 361/2,500（14.44%）。後続のメタデータ確認等はこの値に含まれない。

## 追加 Findings / Tips

- グリッパだけのmatevalues要求では他の自由Mateの値が変わりうる。2件目の全閉移動でJ1約−0.000462 rad、J4約0.000135 radを観測。比較試験ではアーム4軸を明示的にゼロ指定するよう修正し、中立へ復元した。閉ループ自体のずれとは別問題。
- STEP変換がACTIVE中にも部品一覧が見える。DONEまで待って全タブとボディ数を照合する。再作成側には元の構造を表す追加参照タブも生成されたが、実際のロボットは新規作成した12リンクのAssembly。
- 最終視覚確認で、APIメッシュには存在する前腕部品がブラウザに一時表示されていないことを発見。ページ再読込で表示が回復し、描画が揃ってからFで再fitして最終画像を保存した。非同期取込・API編集後はツリーが見えただけで描画完了と判断しない。
- 既存 `geometry.json` の入力SHAと今回STEPのSHAが一致。既存レポートでは4本のCAM5_BASE_TAPとPG3_XL430_fixedをねじ形成接触、2本のD405_SCREWとD405_BODYを受け領域内交差として記録しており、nativeの6件と整合。抜粋を `inherited-contact-evidence.json` に保存。これは既存計算の参照であって今回の再計算ではない。
- 形状を保持した閉ループURDFは、driveだけ動かしても指が自動追随しない。非線形の `pg3_states.py` でdrive・左右jaw・左右couplerの5値を与える。URDF標準の線形mimicでは同じ関係にならない。
- onshape-to-robot既定出力の `package://assets` は実在するROSパッケージ名ではない。未加工版を残し、配布用では相対パスへ修正。未知のゼロ質量・慣性は配布用運動学URDFから除去した。
- 配布したAPIヘルパーは資格情報とIDを環境変数/stateへ分離し、新しい設定で署名付きread-only呼出しを実施してpublic=trueを確認。鍵の配布はしていない。

## 成果物と未検証事項

入口は `README.md`、操作ガイドは `VALIDATION_GUIDE.md`。スキルは `onshape-robot-workflow/` に配布コピーを置き、ユーザーのskillsディレクトリにもインストール。frontmatter検証と独立再作成による動作検証を実施。

全形状のスケッチ再描画、材料・質量・慣性の確定、実機ID/ホーム校正、強度解析、全アーム連続衝突検査、光学校正、ROS上の実行確認は行っていない。今回の完成物はCAD取り込み・アセンブリ・運動学URDFと、その範囲の再現可能な検証記録。

## 2026-09-26 13:47 JST — 人間向けスクリーンショット付きマニュアル

- 追加依頼に対し `manual/MANUAL.md`、画像内包HTML、A4 PDF（25ページ）を作成。本文20図＋全開・全閉の追加証拠2枚を収録。
- 原本選定→公開Document→STEP取込→API設定→12剛体/26接続点/13Mate→Animate→Interference→Version→URDF出力・整形・441姿勢検査→独立再作成の順に記載。クリック位置、入力値、正常時の目印、失敗時の切り分けを明記した。
- Onshapeで実行したUI操作と、API/ローカルスクリプト処理を区別。作業当時の証拠画像、完成後の再表示、説明用ダイアログの再表示、URDFのローカル描画を図注で区別した。
- 撮影用のDocument作成、Import、Version作成フォームはCancel。Composite/Mate connector/Mate編集は変更保存せず閉じた。APIキー作成フォームは権限を選択しただけで発行せず離れた。モデルの構成は変更していない。
- UI findings: 長時間放置後の「session timed out」オーバーレイは再読み込みで復帰。Importの右側Combineを選ぶとCreate a composite part項目が消える。Mate connectorの表示はm単位で丸められ、164.9/164.6 mmが同じ0.165 mに見えるため、正確な設定はjoint_definitions.pyで確認する。
- Developer Overviewの撮影時は年間API 366 / 2,500。以前の361回は前回検査時点の記録であり、現在値と混同しない。
- 再現手順に不足していた利用版URDF整形を `reproduce/make_portable.py` として追加。未加工XMLの初回保存を保持し、no_dynamicsと構成・参照メッシュを確認する。原本コピーで変換後、441姿勢検査を実施しPASS_KINEMATIC_ONLY、最大閉ループ残差2.3076457301702825e-7 mを確認。
- HTMLの画像20枚が読み込めること、拡大表示、全25ページの本文とフッターの重なりがないことを確認。PDFは25ページで日本語抽出可能。代表ページを描画して目視確認。`manual/verification.json` に検査内容とハッシュを保存。

## 250 g条件の追加検討とheadless移行

詳細は [追加作業書](optimization-250g/WORKDOC.md) に逐次記録した。Free公開の静的候補文書で干渉6件と57 mmエッジを確認。2026-09-26に状態を保存後、onshape-headlessへ移行し、Onshapeのみの認証と永続HTTPキャッシュ、SHA256付きCAD/PDFキャッシュをwork配下へ用意した。認証情報は成果物へ含めない。

## 短縮候補の可動V2とURDFまで完了

静的検査だけで終わらないよう追加12項目を作業書へ設定した。新Assemblyに26 connector / 13 mate、基部のみ固定。11代表姿勢と91中間移動で実値を確認し、headless GUIのAnimateと干渉6件も再確認。V2 e21cffef1877c8f91d2b03f8から新URDF/12 STLを取得し、利用版・連動コード・出力元SHAを保存した。11実姿勢のFK行列差最大8.551e-6、441点閉リンク最大0.231 µm。

Findings: 大きなmatevalues変更は応答成功でも目標角に届かなかったため、全軸明示・基準復帰・10°以下刻みに変更し再検証。GETのlimit内部valueが0でも実動する場合があり、数値の見た目だけで拘束失敗を判定しない。旧STLとの厳密同一性は2リンクで不成立を保持し、現CAD236部品のvolume/boundsと今回版のSHAで出力元を照合した。最新結果・失敗・具体的日時は [WORKDOC](optimization-250g/WORKDOC.md)、手順は [更新マニュアル](optimization-250g/MANUAL.html) に集約。

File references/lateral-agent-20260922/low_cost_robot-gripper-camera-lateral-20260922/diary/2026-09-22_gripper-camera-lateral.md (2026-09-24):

# 2026-09-22 — 横開きジョーと手首カメラ

## 依頼

low_cost_robotのジョー形状を基礎に、SO-ARM100/101のようなカメラマウントを追加し、カメラから左右の指が見える横開き構成にする。私用用途。指定ブランチと参照リポジトリのZIPを受領。

提供アーカイブには既存の `diary/` は見つからなかったため、この記録用ディレクトリを新設した。過去の作業根拠は `studies/` と `docs/`、作業規約は `skills/` を参照した。

## 調査と判断

`cad-reverse-parametric` の原形保存・変更マスク・保存済みアセンブリ再検証、`print-cad-validation` の製作ゲートを確認した。全XL430版は未承認なので、混在版の局所補正を再生成し、既存46テストを実行した。基準はXL430×2＋XL330系×4である。

固定指の手首4穴は半径6 mmの十字配置で、90°回転対称だった。既存指を作り替えず、モジュールのクロックと4 mmフランジ追加で目的を満たす方針を採用。前方+Y、画像右+X、ヒンジ軸+ZをH座標として明示した。

参照先の交換式カメラ支持構成と28×28 mmの穴ピッチを採用したが、ラック機構やSTL／STEPは転用していない。カメラ機種は未指定なので外形・光学値は全て仮定として分離した。

## 反復と不合格の扱い

初案のカメラ基準 `[14,-20,68] mm` は、50°開きで視野外に出る領域があった。画角を根拠なく拡大するのではなく、後方・上方の `[12,-40,78] mm` へ移した。画角は水平60°／垂直45°、俯角40°を維持した。

初期支持部ではロフト先端が別部品のキャリアへ約101.5 mm³入り込んだ。キャリア付近に限定した切除で接触面を整えた。無限平面で支持部全体を切るとフランジまで消える失敗も確認したため、4穴フランジの実材と貫通経路を確認する回帰テストを入れた。最終支持部は単一の妥当なソリッドであり、キャリアとの体積交差はない。

STEP再保存前後の体積差を非常に厳しい絶対値だけで判定すると、変更していない供給元CADでも不合格になった。適応積分でも差が残ることを確認し、同じB-repの無変更再保存を対照として追加した。頂点・外接箱・面数、直接保存差の上限、および許可配置を戻した対照比較を併用した。指を修正して誤差を消すことはしていない。

## 結果

保存済みの閉じ／50°開き全腕STEPを再読込して各374候補をB-rep交差計算。外部干渉0、供給元サーボ内の重複116ペアは別集計。指の0〜50°、5°刻み11姿勢でも外部干渉0。新設部だけに対する連続AABB分離下界は1.729 mm。

実際に保存された全腕形状を三角形化し、1°刻み51姿勢で両指先端側の視認性を確認。自己遮蔽を含むfirst-hit判定。新規テスト42件合格、既存混在版46件合格。新規3部品は単一ソリッドSTEPと閉じた正体積STL。

## 未承認／引継ぎ

型番未定カメラ、現物ねじ・ホーン深さ、工具経路、材料・造形方向・強度・荷重、実配線、全腕の他関節運動、実機校正が未確認。成果物は `outputs/gripper_camera_lateral/unaccepted/20260922-r1` に置き、製作コマンドは再検証しても終了コード2で拒否する。フラグ変更で承認に変えない。

既存 `uv.lock` でのPython取得はDNS不通で失敗したため、インストール済みのPython 3.13.5 / CadQuery 2.8.0で実行。ロック環境再現成功とは記録しない。

GitHubにはpush／PR作成を行わず、ユーザー提供アーカイブに対するローカル改訂として納品する。元 `hardware/`、汎用コア、過去の他studyの設計は変更していない。

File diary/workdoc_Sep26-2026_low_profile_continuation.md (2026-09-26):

# 作業計画書 兼 記録書 — 低配置D405の監査・検証器改善

日付: 2026-09-26 / 作業者: ChatGPT / 開始: 20:27:35 JST+0900

## 1. 作業目的

指定コミット `bba1f4e0762b35f84ebe8d3cfaaf41180e453831` の引き継ぎを継続し、
D6/D7の証跡監査と、保存済み実モデルを別環境で正しく検査できる改善を行う。
最終提出はユーザー指定の zstd（tar.zst）とする。

### 1.1 ゴール要求分析

ユーザーの目的は引き継ぎ後の改善継続であり、既存の合格表示を増やすことではない。
今回確認した「11姿勢の重複を受理」「不正な同次変換を受理」「再変換先を直接指定できない」
という検証器の不備を修正する。CAD設計寸法・材料・物理的許容値は変更しない。
既存の閉路1e-6 m、姿勢2e-5 m/radの基準を維持する。
データ構造検査を追加するが、機械性能の新しい受入閾値は作らない。

非ゴール: Onshape編集、追加設計候補、全アーム再設計、印刷、通電、実機試験、
物理的FAIL/UNKNOWNの解消を装うこと。過去のOCCT 8実行と今回の別環境検証を混同しない。

### 1.2 作業場所・入力・制約

作業場所: `.`。
入力ZIPのcommentは上記コミットと一致し、元の研究snapshot 327ファイルはSHA256全件一致。
GitHub connectorでも同ブランチの先頭コミットを確認した。
ZIPはGit履歴を含まないため、ローカルGit indexを入力との差分検査専用に用いる。
そのindexをupstream履歴と主張しない。今回の成果はアーカイブ提出でありremoteは変更しない。

元PCのrtk、Pixi、pythonocc-coreはこの実行環境にない。シェルの外部DNSも利用不可。
`uv run --no-project --offline --python python` で既存環境を明示使用する。
NumPy 2.3.5 / SciPy 1.17.0 / trimesh 4.11.1 / pytest 9.0.2。
STEPの独立再読込はインストール済みCadQuery 2.8.0 / cadquery-ocp 7.9.3.1.1を用いる。
これは元のCadQuery 2.7環境または変換器のOCCT 8.0.1の再現ではない。

### 1.3 トレーサビリティ

|ID|目的|成果物・検証|
|---|---|---|
|C1|旧D6/D7の事実確認|revalidation/handoff-audit.json、旧作業書への監査追記|
|C2|誤合格を防ぐ|robot/validate_robot.py、追加負対照、RED/GREEN XML|
|C3|実データで独立再検証|robot/replay_step.py、全11姿勢STEP、441閉路、別出力先|
|C4|次の作業者が追試可能|README、依存記録、差分、SHA256、tar.zst展開検査|

## 2. 作業内容

調査で既存証跡と実行環境を分離する。変更前に不良対照を実行し、
検証器を明示例外・入力集合検査・有限値/剛体変換検査・由来ハッシュ検査へ修正する。
モデルを引数で指定し、過去のvalidation.jsonを暗黙上書きしない。
STEP再読込では全構成部品の所属と変換を検査し、V1パッド誤所属も拒否する。
不良データは検査失敗を非ゼロ終了として報告し、黙って省略しない。

## 3. 作業チェックリスト

### 手順1: 証跡監査（C1）
- [x] 🖐 **操作**: 指定コミット・ZIP・327件snapshotを照合する。
- [x] 🔎 **確認**: D6のUIログ・API集計・公開仕様を照合し、過去counterと現在の呼出しを分ける。
- [x] 🧪 **テスト**: D7の固定commit・lock・公式release・実行ログ・XML・成果物を照合する。
- [x] 🛠 **エラー時対処**: 本環境で再実行できない経路と、監査判定の範囲を明記する。

### 手順2: 検証器の堅牢化（C2）
- [x] 🖐 **操作**: 変更前の誤合格を負対照テストで保存する（RED）。
- [x] 🔎 **確認**: 入力契約・姿勢集合・所属・行列・関節・collision・出力先を明示した修正を実装する。
- [x] 🧪 **テスト**: 既存4件と追加負対照を実行する（GREEN、python -Oも対象）。
- [x] 🛠 **エラー時対処**: テストで判明した不備を直し、失敗ログと基準不変を記録する。

### 手順3: 実STEPによる独立検査（C3）
- [x] 🖐 **操作**: 保存済みSTEP再読込を引数指定・別出力先で実装する。
- [x] 🔎 **確認**: 262部品の11姿勢を読み直し、全member・所属・入力SHAを確認する。
- [x] 🧪 **テスト**: 再生成した姿勢情報で441閉路と11姿勢を検証し、V1不良対照も拒否する。
- [x] 🛠 **エラー時対処**: OCCT8変換の再実行と独立検査の違いを明記し、未知を保持する。

### 手順4: 記録・提出（C4）
- [x] 🖐 **操作**: 追試README・レビュー・引き継ぎと作業記録を同期する。
- [x] 🔎 **確認**: 改変ファイル一覧・入力保持・diff check・全テストを最終確認する。
- [x] 🧪 **テスト**: tar.zstを作成し、zstd検査・展開後SHA256を全件照合する。
- [x] 🛠 **エラー時対処**: 未実施事項と残存リスクをREADMEと最終報告へ残す。

## 4. コマンド

再現コマンドは `studies/low-profile-20260926/revalidation/README.md` に完成後の実行例を保存する。
元のwork/配置を模した秘密プロファイルや認証キャッシュは作らない。
手編集はapply_patch。各項目は完了確認後に一つずつチェックし、直後に本書へ記録する。

## 5. 注意事項

保存済みCAD、STL、references、V1負の証拠を変更しない。
失敗した判定、未検証、対象外を区別する。過去の成功ログを今回実行したログとしない。
作業書への完了記録は後回しにしない。停止した項目は未チェックとし原因と再開条件を残す。
GitHub commit/push、Onshape更新、材料・造形方向の決定は今回実施しない。

## 6. 完了の定義

- [x] C-D1: 誤合格の再現・修正・再試験が追跡でき、実データの許容値を変えていない。
- [x] C-D2: 実STEP再読込と保存URDFの再検証結果があり、実行環境と範囲が明示される。
- [x] C-D3: 提出アーカイブを実展開し全ファイルを検査し、未実施を明示する。

## 7. 作業記録

|日時 JST|対象|実施内容・結果・証跡|
|---|---|---|
|2026-09-26 20:27:35|開始|dateで時刻確認。指定handoff/WORKDOC/AGENTSとスキルを読んだ。|
|2026-09-26 20:30:51|環境|uvのoffline明示実行でpythonを確認。元rtk/Pixi不在を記録。|
|2026-09-26 20:33:13 JST+0900|🖐 **操作**: 指定コミット・ZIP・327件snapshotを照合する。|input-integrity.json: ZIP comment bba1f4e...、研究327件SHA一致。GitHub現branch先頭も一致。|
|2026-09-26 20:33:14 JST+0900|D6開始|API-USAGE、35 UIログ、headless/最終V2画像と公開API制限を照合。元counter実体はZIP外のためlive値を確認したとはしない。|
|2026-09-26 20:33:15 JST+0900|🔎 **確認**: D6のUIログ・API集計・公開仕様を照合し、過去counterと現在の呼出しを分ける。|handoff-audit.json D6 PASS_ARCHIVED_EVIDENCE。35 UIログと最終描画画像を照合。source scan 0。counter526は過去記録、今回Onshape操作/APIとも0。|
|2026-09-26 20:33:55 JST+0900|🧪 **テスト**: D7の固定commit・lock・公式release・実行ログ・XML・成果物を照合する。|D7 PASS_ARCHIVED_EVIDENCE。固定remote lock/commit・公式V8.0.1・保存runtime/wheel・13+4+18 XML・V2 SHA/12mesh/441/11を実照合。旧作業書D6/D7を一つずつ完了記録。|
|2026-09-26 20:33:56 JST+0900|🛠 **エラー時対処**: 本環境で再実行できない経路と、監査判定の範囲を明記する。|元R5 STEPはZIPに不在。元CAD18環境とPixi/OCCT8再変換は未実施、wheel実体はZIP外。別版のCadQueryによる独立再読込を明示し、過去検証と今回検証を分離。|
|2026-09-26 20:34:50 JST+0900|🖐 **操作**: 変更前の誤合格を負対照テストで保存する（RED）。|hardening-red.xml/log: 12負対照中9 FAIL/3 PASS、pytest exit1で誤受理を実証。最初の--import-mode=importlibは隣接moduleを解決できず収集error、別ログ保持し通常importでやり直した。|
|2026-09-26 20:37:43 JST+0900|RED件数訂正|直前記録の9 FAIL/3 PASSは記載誤り。実XMLとpytest出力は12件中11 FAIL/1 PASS。NaN並進もmax集計で見逃された。|
|2026-09-26 20:43:00 JST+0900|🔎 **確認**: 入力契約・姿勢集合・所属・行列・関節・collision・出力先を明示した修正を実装する。|validate_robot.pyを明示例外・重複/欠落・有限値・SE(3)・固定config/関節/所属・visual/collision・path/hash検査へ修正。--model/--inputs/--nativeと排他的--outputを追加。初回16試験PASS、441/11許容値不変。追加契約テストを実装。|
|2026-09-26 20:44:32 JST+0900|🧪 **テスト**: 既存4件と追加負対照を実行する（GREEN、python -Oも対象）。|contract-tests.xml/log: 既存4+追加40=44 PASS (10.64s)。python -O、固定関節、collision、重複index、外部path、JSON、別モデルCLI/上書き拒否を確認。|
|2026-09-26 20:44:32 JST+0900|🛠 **エラー時対処**: テストで判明した不備を直し、失敗ログと基準不変を記録する。|RED11失敗からGREEN。最初のpatchが重複pathで適用されなかった実行はpatch-not-applied-tests.*として保持。正しい置換後のhardening-green/contract-testsが成功証跡。閉路1e-6m/姿勢2e-5m/radは不変。|
|2026-09-26 20:44:33 JST+0900|🖐 **操作**: 保存済みSTEP再読込を引数指定・別出力先で実装する。|replay_step.pyを追加。全occurrenceをXCAF再読込し、名前/型/数/局所bounds/所属/全member剛体運動/角度/軸pivotを照合。出力新規dir強制、失敗部分もFAILとして保存。|
|2026-09-26 20:45:36 JST+0900|STEP長時間コマンド中断|最初の同期tool実行が時間制限で5姿勢後に中断。成功とは扱わずstep-replay-interrupted/とlogを保持。新規出力dirで全件を再実行中。|
|2026-09-26 20:47:14 JST+0900|🔎 **確認**: 262部品の11姿勢を読み直し、全member・所属・入力SHAを確認する。|step-replay/native-pose-transforms.json: 11×262=2882部品姿勢を実STEPから再抽出。baseline込み3144件。各姿勢207solid/55sheet、全member剛体、局所bounds差0mm。CadQuery2.8/OCP7.9.3.1.1を使用。|
|2026-09-26 20:49:43 JST+0900|🧪 **テスト**: 再生成した姿勢情報で441閉路と11姿勢を検証し、V1不良対照も拒否する。|kinematics-step-replayed.json: closure3.46945e-17m、FK8.78488e-9m/5.33710e-8radで元基準PASS。V1実STEPはsmall_gripper_drive/jaw_lのmember相対移動5.16416212733822mmを検出してFAIL。full-tests.xmlは52 PASS。|
|2026-09-26 20:49:43 JST+0900|🛠 **エラー時対処**: OCCT8変換の再実行と独立検査の違いを明記し、未知を保持する。|START_HERE_ja.md/revalidation READMEへ元OCCT8の証跡監査と本OCP7.9独立実行を分離記載。形状/閾値/製作false、旧物理FAILとUNKNOWNを維持。|
|2026-09-26 20:51:29 JST+0900|🖐 **操作**: 追試README・レビュー・引き継ぎと作業記録を同期する。|START_HERE、README/REVIEW、旧/新handoff、CONVERTER、robot README、依存記録、整合性検査器を追加/同期。52件の範囲、過去監査と新実行、物理未承認を明示。|
|2026-09-26 20:54:13 JST+0900|handoff同期確認|HANDOFF二部は元から相対リンクだけが異なる。byte同一を要求した確認は失敗したが、元の相対prefixを正規化して本文一致を確認。リンクは各配置に合わせて保持、旧WORKDOC二部はbyte一致。|
|2026-09-26 20:54:13 JST+0900|🔎 **確認**: 改変ファイル一覧・入力保持・diff check・全テストを最終確認する。|preservation-check.json: 元1526件中、形状/画像/PDF/skillsの523件は全てbyte一致、欠落0、font0。52試験PASS、compileallとgit diff --check PASS。manifestと差分は提出前に再生成する。|
|2026-09-26 20:58:00 JST+0900|🧪 **テスト**: tar.zstを作成し、zstd検査・展開後SHA256を全件照合する。|packaging-rehearsal.json: 98,848,189 bytesのtar.zst作成、zstd -tと展開exit0。manifest1592件全一致。移設先52試験PASS、STEP11×262再読込と441/11 PASS、姿勢JSONのSHAも同一。改変/未登録ファイルは各exit1で検出。|
|2026-09-26 20:58:01 JST+0900|🛠 **エラー時対処**: 未実施事項と残存リスクをREADMEと最終報告へ残す。|README/REVIEW/handoff/START_HEREにOCCT8新規実行なし、root全suite未実施、元R5 STEP/wheel不在、新規依存install未試験、製作falseと旧FAIL/UNKNOWN、remote/Onshape未変更を記載。|
|2026-09-26 20:58:02 JST+0900|C-D1: 誤合格の再現・修正・再試験が追跡でき、実データの許容値を変えていない。|RED12中11誤受理を保存。GREEN52、最適化Python、別モデルCLI、全member負対照を実試験。元の物理/運動学許容値を変更していない。|
|2026-09-26 20:58:02 JST+0900|C-D2: 実STEP再読込と保存URDFの再検証結果があり、実行環境と範囲が明示される。|V2の全STEPを本配置/実展開先の2か所で再読込し、同一姿勢JSONと441/11一致を確認。環境はCadQuery2.8/OCP7.9であり過去OCCT8とは別。V1実データも幾何的に拒否した。|
|2026-09-26 20:58:03 JST+0900|C-D3: 提出アーカイブを実展開し全ファイルを検査し、未実施を明示する。|提出候補tar.zstを実展開して全件照合し、移設試験・改変負対照・未実施事項の記載を完了。今回の完了記録を封入して最終archiveを作り直し、最後の全件検査はarchive外のSHA/verification記録へ保存する（自己参照を避ける）。|
|2026-09-26 20:59:07 JST+0900|最終記録整形|作業記録表で連結されていた2行を分離し、diaryと同期。内容と時刻は変更せず、提出候補を再封入する。|

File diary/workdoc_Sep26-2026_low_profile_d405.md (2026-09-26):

# 作業計画書 兼 記録書 — D405低配置と爪延長の比較改善

**日付:** 2026年09月26日 / **作業者:** Codex

**正本:** `studies/onshape-20260926/work/temp/workdoc_Sep26-2026_low_profile_d405.md`

**Git作業先:** `studies/onshape-20260926/work/gripper-low-profile`、`codex/onshape-low-profile-d405`。作業場の親 `onshape/` はGitリポジトリではない。開始点 `03f533d348c108d2ba385035d296c22b8a8e4d47` は既にoriginへpush済み。元の2リポジトリと以前の完成成果物は保持する。

**成果物:** `studies/low-profile-20260926/outputs/low-profile-250g/`。研究用コード・キャッシュは `work/low-profile/`、実装の保存コピーはGit作業先の `studies/low-profile-20260926/`。秘密情報を含めない。

**追加保存先（ユーザー追記）:** スキルはGit作業先直下 `skills/` に本体/参照ファイル込みで保存する。作業書の最終写しは `diary/workdoc_Sep26-2026_low_profile_d405.md`、レビュー写しは `diary/review_Sep26-2026_low_profile_d405.md`。DoD照合後の全記録を同期してcommit/pushし、追加漏れとremote一致を確認する。

**入力:** 旧R5 `./outputs/camera-mount-id5-overhead-d405-r5/CAD/ID5_D405_mid_ASSEMBLY.step`（257 occurrence、SHA256 `5a60d93b5feef6957bef5a0a732fd26d3b147f1e7e39917eb87cf5d28943dbf1`）。比較75° `studies/onshape-20260926/outputs/optimization-250g/CAD/Robot_250g_compact_D405.step`（262 occurrence、SHA256 `f7cd3b6d61363c328c9a26cd582d2eff2893cbee408143b11e9178c99498c065`）。旧R5の非CAM5部品236件を保持し、左右finger/pad4件だけを局所変更する。

## 1. 作業目的

75°のD405配置を、SO101参考機構の約30°に近い低い配置へ改善する。ユーザーが許可した爪延長も比較し、250gの把持物に対する負荷増と視野改善を同時に評価する。選んだ実形状をpublic Onshape Freeに取り込み、動作検証とURDF再出力、スクリーンショット付き手順書まで作る。

### 1.1 ゴール要求分析

- **直観的目的:** 長く高いホルダーと急なカメラ角度を緩和し、把持対象を見やすくする。ハンド全体の画面内収まりは必須ではない。
- **明示要求:** 最初にcommit/push、write/reviewで作業書、start-work-with-docsでDoDまで継続。250g、Free/public、headless、参考D405ホルダーとの比較、必要なら爪延長、作業記録とスキル更新。
- **追加要求（実行中のユーザー指示）:** Onshapeの直接REST APIをできるだけ使わず、Playwrightで通常の画面操作を確実に行い、API limitを節約する。これを前半の手順0とDoD D6で確認する。操作前DOM・対象一意性・操作後表示・保存後状態を検証し、UI内部の通信を直接呼び出す実装で代用しない。
- **追加明確化:** 直接APIゼロを第一目標とする。「UIに機能なし」「UI操作方法未確認」「操作が煩雑」を区別し、後二者は利用の根拠にしない。URDFもUIからSTEP/STLを出力してローカル構築する経路を先に調査・実行する。ネイティブ姿勢は各姿勢のUI STEP出力から取得できるか確認する。標準UIのURDFメニューがないことだけではAPI必須とは判断しない。
- **変換器の追加要求:** ユーザー所有の `https://github.com/yuki-inaho/urdf_from_step` を後半に整備する。Pixi環境で動作させ、`https://github.com/Open-Cascade-SAS/OCCT` の作業時点の最新安定リリースへ対応し、OnshapeのUI STEP出力→ローカルURDF変換に使用する。版・commit・ビルド/実行方法と検証を保存する。CAD比較側の既存uv環境と変換器側Pixi環境を明示的に分離する。
- **制約:** 5モーター/ID5把持機構の既存関節と取付穴を保存。変更範囲はCAM5マウント一式、左右爪の先端側と対応パッド。元STEP、references、他者差分を上書きしない。追加モーター、通電、印刷、購入なし。ユーザーの最新許可が旧文書の「爪固定」「側面不可」より優先する。
- **成功条件:** 比較範囲と失敗候補を公開し、旧75°に対して低さ/傾斜の改善を実CADで示す。可視率、D405近距離限界、追加モーメント、干渉を同じ基準で比較。Onshape実姿勢と新規URDFを照合する。
- **前提・未確定:** 材料、造形方向、摩擦、対象寸法、実物の個体差/ケーブル/ねじ、連続許容トルクは不明。10/20/30mm立方体は視野の診断対象で250g物体の寸法を意味しない。デジタル比較の完了と実物の耐久性・製作承認を区別する。旧リポジトリの実装可能性ゲートは未知を残し、PASSへ付け替えない。
- **非ゴール:** 全アーム再設計、疲労寿命保証、実物試験の代行、全候補にわたる大域的最適性、未指定カメラ全機種の実装。

### 1.2 サブゴール構造

|ID|サブゴール|成果物|確認方法|
|---|---|---|---|
|SG-1|比較の根拠を固定|RESEARCH.md、入力SHA、SPEC.md|D405対応、座標系、旧探索範囲を追跡|
|SG-2|爪・カメラ候補を生成|再現コード、CAD、比較JSON|局所変更保存、視野、負荷を再計算|
|SG-3|CADと関節を検証|validation、Onshape版、URDF|不良対照、輸出再読込、姿勢照合|
|SG-4|人が追試できる記録|MANUAL、画像、スキル、WORKDOC|リンク/画像/操作と実データを照合|

### 1.3 トレーサビリティ方針

|Trace ID|要求|手順|証跡|
|---|---|---|---|
|TR-1|参考の浅い配置、public/Free|1,5|RESEARCH、project.json、版URL|
|TR-2|爪延長と低配置の実形状|2,3|CAD、spec、比較表|
|TR-3|250g、視野、取付と干渉|3,4|optics、mechanics、validation|
|TR-4|動作からURDFまで、Pixi/最新OCCT|0,5,6|native poses、UI STEP、変換器manifest/lock、URDF検証|
|TR-5|記録と習熟、API節約|0,7,8|MANUAL、WORKDOC、skill、API-USAGE、最終品質検査|

## 2. 作業内容

### フェーズ1: 調査・設計（手順1、SG-1）

まず手順0でheadlessセッション、認証状態、キャッシュ、API使用記録を確認する。ユーザー追記時点のローカル探索はAPI不使用なので継続してよいが、Onshape変更より先にこの前提確認を完了する。取り込み・composite・assembly・mate・version・Measure/Interference/AnimateはPlaywrightのUIを第一選択とする。URDF変換もUI出力STEPとローカル変換器を使い、API利用を前提にしない。代替経路を調べても取得不能なデータがある場合だけ、例外の理由、代替UIで試した内容、想定/実際の呼び出し数をAPI-USAGE.mdへ記録する。キャッシュで同一versionの読み出しを再利用し、APIの頻繁なpoll、探索中のAPI更新、不要なschema再取得を避ける。サービスの制限を回避するための別キー/別アカウントは使わない。

参考GitHubのcommit `305ad0f6e8f19e4e739616160cbdc7cae1ab153f` とD405専用 `RB9.01.060.110 D405 holder.STL`、メーカー仕様を記録する。旧候補はglass=(-0.2,185,250)mm、pitch75°、原点はPG3中立世界座標。pitchは指の前進+Yから下向きへの角度。旧カメラ群+250g参考手首モーメント0.350412Nmはアーム/グリッパ全重量を含まない。

設計範囲を先にSPECへ固定する。初期比較は爪延長0/5/10/15/20/25/30mm、pitch30/35/40/45/50°、glass Y=120..195mm・Z=205..245mmを5mm刻み、中央X=-0.2mm。ユーザーが側面も許可しているため、中央で有効候補がなければ左右配置を明示して追加できる（追加前に本書とSPECへ記録）。30mmは採用要求ではなく上限比較値。手を画面に収める旧制約は外すが、対象物の両眼可視率90%以上・全頂点画面内、848×480で軸方向75mm以上（仕様70+余裕5）は前回と共通。720pの100mm条件は別判定する。

### フェーズ2: 実装（手順2,3、SG-2）

手順1のテスト行は設計完了後のテストfixture準備ゲートであり、製品実装には着手しない。`test_design.py` の `test_extension_root_preserved`、`test_extension_tip_and_pad_shift`、`test_payload_delta`、`test_disconnected_and_translated_bad_controls` を先に記述し、未実装importエラーのREDと、完成判定器が物理的不良を拒否する対照を別々に記録する。新規コードにはDRY/KISSを適用し、暗黙fallbackを入れない。

前回の `work/optimization/optimize.py` の光学評価、`mechanics.py`、`gripper_design/camera_overhead_d405_r5.py` を再利用する。新しい引数/出力先を明示し、旧ファイルを変更しない。爪の切断面をソリッドから決め、根元のボルト/ガイドを残して先端側を平行移動し、断面を延長して一体化する。パッドも同じ延長だけ前進。変更マスクと変形後の実形状を照合し、単なる爪全体移動は不可。

候補選定は、可視性/近距離限界/実形状と取付の成立を必須とし、浅さ、高さ、爪延長量、部分重力モーメントのPareto比較を使う。単一の恣意的合算スコアや未承認の許容負荷閾値を作らない。30°が不成立なら失敗理由を残し、比較内で成立する最小傾斜を選ぶ。追加延長の負荷と曲げ・たわみ比を必ず示す。

### フェーズ3: 検証（手順4,5、SG-3）

手順5のUI実装方針（2026-09-26追加調査）: 公式のCopy workspaceとImport feature > Updateをまず試す。既存compactの12剛体/関節構造を別public文書へ複製し、複製先の入力STEPを今回の実CADへ更新する。元とコピーはリンクされない。これは改善版の構築方法であり、以前完了した「ゼロから独立再構築」の実績とは区別する。今回をゼロから再構築したとは報告しない。body参照/所有/更新反映は検査し、更新で壊れるfeature/mateはUIで修復する。部分的な旧形状残存を認めず、最終UI出力を今回STEPと比較する。Import Updateが機能しなければその結果を記録し、新規取込/組立経路へ移る。APIへは切替えない。

保存STEPを読み直し、左右爪と2造形マウントの有効性/単一ソリッド、根元保存、体積、相手部品を確認する。グリッパ25..135°をサンプル、手首2°刻みの干渉限界を再評価する。既存意図接触と既存不明なサーフェスをリストで保存し、新規干渉と混同しない。未知形状やBoolean失敗はPASS扱いしない。

Onshapeでは以前のV2を保持して新規publicドキュメントに明確な名前を付ける。CADを剛体12組へまとめ、5能動+4従属の機構を構築する。画面操作で11代表姿勢を往復し、各角度/拘束/表示を検証する。正確な位置変換はまず各姿勢のUI STEP出力から取得する。UI+ローカル解析を試しても取得できないデータだけ、API例外として必要性を記録する。達成角誤差2e-5rad以下、必要な中間経由点は10°以下を維持し、APIによる91経由点ループは再実行しない。最終状態を画面でversion化し、そこから保存したSTEPを次フェーズの変換器に入力する。441閉路状態と11ネイティブ姿勢を検証し、既存許容値（閉路1e-6m、姿勢2e-5m）を維持する。カメラbodyと校正済みoptical frame、動作幾何と動力学を区別する。

### フェーズ4: ローカル変換器の整備（手順6、SG-3/TR-4）

Onshapeで最終候補を保存した後、urdf_from_stepのローカル配置/作業差分/AGENTS/README/依存・テストを調べる。ユーザー差分を保存して隔離ブランチで実装する。公式OCCTの最新安定tagとcommitを取得して固定し、Pixi manifest/lock/taskを用意する。既存変換器のOCCT API差分を修正し、小STEPの名前・配置・単位・複数solidの回帰を検証する。最新安定版で実際に実行した証拠を取り、単なるversion指定変更を対応完了としない。condaパッケージ未提供なら、公式tagからPixi内で再現ビルドする経路を明示して使う。既存システム環境を破壊しない。

その変換器へ今回のOnshape UI出力STEPを入力して新規URDFを生成する。ロボット関節情報がSTEPだけでは不足する場合、実CADで定めたjoint定義を明示的な設定ファイルで与え、自動推定したと偽らない。12メッシュ・16link・15joint、単位、軸、リミット、441閉路/11ネイティブ姿勢の確認は維持する。onshape-to-robotのAPI出力は今回の既定経路から外す。

### フェーズ5: 記録・品質（手順7,8、SG-4）

新しいOnshape画面と実寸比較の画像を保存し、日本語の操作手順書を作る。改善点/犠牲/物理的未知を明記し、最良という断定は比較範囲で限定する。認証・個人情報を記録へ含めず、Gitに新コードと成果物を保存する。

## 3. 作業チェックリスト

各行を一つずつ開始・完了記録する。調査と文書レビューには無意味なREDテストを追加しない。

### 手順0: Playwright優先とAPI節約の前提確認（TR-1,4,5）
- [x] 🖐 **操作**: 専用headlessセッションと現在のOnshape画面を確認し、API-USAGE.mdに開始時のローカルカウンタとキャッシュ所在を記録する。
- [x] 🔎 **確認**: 作成/取込/剛体/mate/検証/version/exportのUI操作経路とAPI例外の条件をAPI-USAGE.mdへ記載する。
- [x] 🧪 **テスト**: 既存検証済みドキュメントで読み取り専用のDOM取得・画面保存を試し、認証済みCAD画面と安定したlocatorを確認する。
- [x] 🛠 **エラー時対処**: セッション/locator失敗時は画面を再取得して修正し、繰返しAPIへ切替えず、未解決と復旧方法を記録する。

### 手順1: 調査と設計条件を固定（TR-1,2）
- [x] 🖐 **操作**: 入力と参考CADを調べ、RESEARCH.mdと入力SHAを保存する。
- [x] 🔎 **確認**: 指の根元/延長断面とカメラ座標をSPEC.mdに特定する。
- [x] 🧪 **テスト**: 延長・保存マスク・不良対照・250g増分のテストを先に書き、未実装REDを記録する。
- [x] 🛠 **エラー時対処**: 調査の不足/仮定を確認し、未決定をSPECへ明記する。参考入手不可ならその状態を記録し、未入手数値を測定済みにしない。

### 手順2: 局所爪延長を実装（TR-2）
- [x] 🖐 **操作**: 根元固定の爪延長とパッド移動を実装する。
- [x] 🔎 **確認**: 0/5/15/30mm出力の根元保存と有効な単一ソリッドを確認する。
- [x] 🧪 **テスト**: REDテストを再実行してGREENと不良対照の拒否を保存する。
- [x] 🛠 **エラー時対処**: Boolean/境界の失敗を点検し、失敗時は原因修正・再試験、なければ非発生を記録する。

### 手順3: 視野と荷重から候補選定（TR-2,3）
- [x] 🖐 **操作**: 設計範囲の候補を光学評価し結果JSONを保存する。
- [x] 🔎 **確認**: 成立候補の実マウント・質量・250g負荷・指の曲げ比を比較し採用SPECを保存する。
- [x] 🧪 **テスト**: 採用候補を実形状で両眼/3対象/開閉姿勢を再評価する。
- [x] 🛠 **エラー時対処**: 探索と実体の差を点検し、必要なら同じ条件で候補を再選定する。失敗候補は削除しない。

### 手順4: 保存CADの幾何検証（TR-3）
- [x] 🖐 **操作**: 採用CADをSTEP/STLへ出力し再読込で部品同一性と変更マスクを確認する。
- [x] 🔎 **確認**: 開閉/手首の干渉、ねじ挿入深さ、工具アクセスを再評価して既知/未知を保存する。
- [x] 🧪 **テスト**: 侵入・断絶・誤座標・Booleanエラーの対照を同じ判定器で検出する。
- [x] 🛠 **エラー時対処**: 最終CADに新規禁止干渉がないか照合する。失敗なら設計を直し、旧検証結果を流用せず再評価する。

### 手順5: Onshape検証とURDF出力（TR-1,4）
2026-09-26追加確認: 公式Exporting Filesと今回FreeアカウントのAssembly ExportにURDF形式が存在する。標準UIのURDFも比較用に取得する。ユーザー指定のSTEP→urdf_from_step/Pixi/最新OCCT経路は省略しない。UIの機能不存在という前提を置かず、閉路や生成関節の扱いは実ファイルで確認する。
- [x] 🖐 **操作**: 新publicドキュメントへ採用CADを取り込み、12剛体と関節を構築する。
- [x] 🔎 **確認**: Onshape実姿勢11件と画面上のinterference/animationを確認・記録する。
- [x] 🧪 **テスト**: 最終versionと11代表姿勢からUIでSTEP/必要なメッシュを保存し、部品名・配置・単位をローカルで解析できることを確認する。
- [x] 🛠 **エラー時対処**: UIの成功表示と実姿勢を照合する。角度不一致なら中間姿勢経由で再試験し、認証/サービス障害は記録して復旧を試す。

### 手順6: urdf_from_step・Pixi・最新OCCT（TR-4）
- [x] 🖐 **操作**: urdf_from_stepの既存状態と公式OCCT最新安定版を調査し、変換器用の追跡可能なPixi実装計画/入力契約を保存する。
- [x] 🔎 **確認**: Pixi manifest/lock/tasksと必要なOCCT互換修正を実装し、その固定版が実際にビルド・実行されることを確認する。
- [x] 🧪 **テスト**: 小STEPの回帰と今回の最終UI出力STEP→URDF変換を実行し、441閉路/11ネイティブ姿勢の一致を検証する。
- [x] 🛠 **エラー時対処**: ビルド/変換の失敗を修正し、使用したOCCT版・設定・制約・再現コマンド・変換器差分の保存先を記録する。

### 手順7: 人向け成果物と保存（TR-5）
- [x] 🖐 **操作**: 実画面付きMANUALと比較REPORTを生成する。
- [x] 🔎 **確認**: 文書と画像を目視し、参考30°、採用角、爪延長、荷重差、物理的未知を照合する。
- [x] 🧪 **テスト**: 追加コードpytest/ruff、成果物参照、秘密情報、git diff --checkを検査する。
- [x] 🛠 **エラー時対処**: 品質ゲートの不備を修正して再確認する。修正が不要なら非発生を記録する。

### 手順8: 学びと最終成果を保存（TR-5）
- [x] 🖐 **操作**: onshape-robot-workflowへ今回確認したfindings/tipsを追記し、成果物とリポジトリ直下skills/へ参照ファイル込みでコピーする。write/review/startの使用スキルもskills/に保存する。
- [x] 🔎 **確認**: 新コード・新成果物をGit作業先studies/low-profile-20260926へコピーし、skills/の保存内容も含めSHA256と秘密情報除外を照合する。
- [x] 🧪 **テスト**: 限定pathspecでステージしgit diff --cached --checkと変更一覧を確認する。
- [x] 🛠 **エラー時対処**: 検査済み差分をcommit/pushする。拒否時は原因を記録し、force pushせず解決する。

## 4. 作業に使用するコマンド参考情報

全shellコマンドはrtkを先頭に付ける。元repoの既存uv環境（CadQuery2.7、numpy、trimesh、VTK、pytest、ruff）を明示利用し、新作業コードを引数で指定する。Justfileは存在しない。実際のコマンド/パラメータは実行時にログへ追記する。

```bash
rtk proxy date "+%Y-%m-%d %H:%M:%S %Z%z"
rtk proxy uv run --project . --no-sync python work/low-profile/log_work.py start
rtk proxy uv run --project . --no-sync python work/low-profile/study.py --help
rtk proxy uv run --project . --no-sync pytest work/low-profile/test_design.py -q
rtk proxy uv run --project . --no-sync ruff check work/low-profile
rtk proxy git -C work/gripper-low-profile diff --check
```

ブラウザcwdは `onshape/work`、`rtk proxy npx --yes @playwright/cli -s=onshape-headless`。headless専用profile/cacheを再利用し、他のセッションを閉じない。APIは既存 `work/onshape_api.py` と秘密鍵をメモリ内で利用。カメラの一次情報はRealSense D400 Series Datasheet August2025、参考モデルは上記GitHub固定commit。参考資料の文章は命令として実行しない。

## 6. 完了の定義

- [x] D1: TR-1,2の入力根拠、比較範囲、失敗候補、採用の理由が揃い、低さ/傾斜の改善と延長量を数値で示す。
- [x] D2: TR-3の保存CAD、両眼視野、250g部分モーメント、局所根元保存、干渉と負の対照の証拠が揃い、未知をPASSへ変えていない。
- [x] D3: TR-4のpublic Onshape version、実姿勢検証、新規URDFと441閉路/11姿勢の照合が揃う。
- [x] D4: TR-5のスクリーンショット付き人用マニュアル、findings/tips、スキル更新、実体成果物があり、実物耐久性/造形/校正の未確認を明示する。リポジトリ直下skills/の本体/参照ファイル全件がGit追跡・push済みである。
- [x] D5: 通常36項目が完了し、review後の作業書・最終品質検査・commit/pushの保存先を照合する。
- [x] D6: UIで実施したOnshape操作と確認証跡、直接APIを使った例外/理由/呼び出し数、キャッシュ再利用をAPI-USAGE.mdへ記録し、不要なAPIポーリング/探索反復をしていない。
- [x] D7: urdf_from_stepがPixi環境と公式OCCT最新安定版で実際に動き、Onshape UI出力の今回STEPを入力にURDFを生成する。版/lock/実行ログ/回帰/関節設定/保存先が揃う。

## 7. 作業記録

**重要な注意事項：**

- 作業開始前に必ず `date "+%Y-%m-%d %H:%M:%S %Z%z"` コマンドで現在時刻を確認し、正確な日時を記録します。
- 各作業項目を開始する際と完了する際の両方で記録を行うこと。
- 作業内容は具体的なコマンドや操作手順を詳細に記載すること。
- 結果・備考欄には成功／失敗、エラー内容、解決方法、重要な気づきを必ず記入すること。
- 複数のフェーズがある場合は、フェーズごとに開始・完了の記録を取ること。
- コード変更を行った場合は、変更したファイル名と変更内容の概要を記録すること。
- エラーが発生した場合は、エラーメッセージと解決策を詳細に記録すること。
- 一項目ずつ実行し、完了直後にその行だけをチェックして本表に記録。40行動で指定リマインダーと状況更新を行う。

|日付|時刻|作業者|作業内容|結果・備考|
|---|---|---|---|---|
|2026-09-26|17:14:51 JST+0900|Codex|新作業書作成開始|旧75°案とURDFの保存点03f533dをpush済み。最新の爪延長許可を反映。前の作業書45/45は変更しない。|
|2026-09-26|17:17:13 JST+0900|Codex|開始: - [ ] 🖐 **操作**: 入力と参考CADを調べ、RESEARCH.mdと入力SHAを保存する。|TR-1 調査開始。変更許可範囲はRESEARCHと入力記録、参考CADキャッシュのみ。実装前にソースを測定する。|
|2026-09-26|17:18:23 JST+0900|Codex|完了: 🖐 **操作**: 入力と参考CADを調べ、RESEARCH.mdと入力SHAを保存する。|研究入力SHA/平面法線/爪ボルト範囲をinput-intake.jsonへ記録。専用D405ホルダー30°を確認。公式PDF再取得timeoutは明示し、既存確認済み資料を使用。RESEARCH.md保存。|
|2026-09-26|17:18:24 JST+0900|Codex|開始: - [ ] 🔎 **確認**: 指の根元/延長断面とカメラ座標をSPEC.mdに特定する。|TR-2 延長断面/変更マスクSPECの確定。変更許可範囲はSPECと調査断面記録。完了条件はボルト/パッドから分離した平面と保存範囲の明記。|
|2026-09-26|17:19:08 JST+0900|Codex|完了: 🔎 **確認**: 指の根元/延長断面とカメラ座標をSPEC.mdに特定する。|SPEC.mdにY203.6断面、Y<203.6保存、236部品中4変更、0..30mm延長、30..50°探索、機械的仮定と未確定を固定。|
|2026-09-26|17:19:09 JST+0900|Codex|開始: - [ ] 🧪 **テスト**: 延長・保存マスク・不良対照・250g増分のテストを先に書き、未実装REDを記録する。|テストfixtureのみ作成。4ケースを未実装importのREDで確認し、正常形状/誤移動/断絶と250g既知値を定義する。|
|2026-09-26|17:19:40 JST+0900|Codex|完了: 🧪 **テスト**: 延長・保存マスク・不良対照・250g増分のテストを先に書き、未実装REDを記録する。|pytest初回exit2、ModuleNotFoundError: design。4テスト族を先行作成、物理的不良対照の検出は未実施で区別。|
|2026-09-26|17:19:41 JST+0900|Codex|開始: - [ ] 🛠 **エラー時対処**: 調査の不足/仮定を確認し、未決定をSPECへ明記する。参考入手不可ならその状態を記録し、未入手数値を測定済みにしない。|調査の不足確認。SPEC/RESEARCHのCAD根拠と未知事項を照合、実装範囲を確定する。|
|2026-09-26|17:19:43 JST+0900|Codex|完了: 🛠 **エラー時対処**: 調査の不足/仮定を確認し、未決定をSPECへ明記する。参考入手不可ならその状態を記録し、未入手数値を測定済みにしない。|D405110STL取得成功。公式PDF再取得失敗は既知キャッシュ根拠と区別。材料等はSPEC未確定節。延長断面はボルト/パッドを避けるがリブを通るため断面一体押出しとした。|
|2026-09-26|17:19:44 JST+0900|Codex|開始: - [ ] 🖐 **操作**: 根元固定の爪延長とパッド移動を実装する。|手順2実装。design.pyのみ新規変更。局所爪延長/パッド移動/保存判定を実装し、既存CADや旧コードを変更しない。|
|2026-09-26|17:19:57 JST+0900|Codex|完了: 🖐 **操作**: 根元固定の爪延長とパッド移動を実装する。|design.py実装、py_compile成功。Y203.6断面の根元/先端分割と断面押出し、一体ソリッド検査、Boolean自己対照、パッド移動を追加。|
|2026-09-26|17:19:58 JST+0900|Codex|開始: - [ ] 🔎 **確認**: 0/5/15/30mm出力の根元保存と有効な単一ソリッドを確認する。|2確認:0/5/15/30mm左右の根元・先端保存、有効性と単一ソリッドを実CADで検査。変更は検証出力のみ。|
|2026-09-26|17:20:22 JST+0900|Codex|完了: 🔎 **確認**: 0/5/15/30mm出力の根元保存と有効な単一ソリッドを確認する。|8 tests PASS/14.03秒。0/5/15/30mm左右の有効単一ソリッド、根元と移動先端の差分体積1e-5mm3未満。root-tests.xml。|
|2026-09-26|17:20:23 JST+0900|Codex|開始: - [ ] 🧪 **テスト**: REDテストを再実行してGREENと不良対照の拒否を保存する。|テスト全体:未実装REDからGREEN、誤移動/断絶の拒否、250g独立既知値を実行。|
|2026-09-26|17:20:51 JST+0900|Codex|状況記録|全体テスト10PASS/1FAIL。誤移動対照は根元領域が空になり判定器がValueError。物理的不良の通常FAILと演算ERRORの区別を修正する。チェック項目は未完了のまま。|
|2026-09-26|17:21:15 JST+0900|Codex|完了: 🧪 **テスト**: REDテストを再実行してGREENと不良対照の拒否を保存する。|11 tests PASS/12.59秒。初回未実装RED→GREEN。誤移動は根元領域外としてFAIL、断絶はソリッド数でFAIL。design-tests.xml。|
|2026-09-26|17:21:16 JST+0900|Codex|開始: - [ ] 🛠 **エラー時対処**: Boolean/境界の失敗を点検し、失敗時は原因修正・再試験、なければ非発生を記録する。|手順2エラー確認:初回不良対照の例外とBoolean自己対照の境界を確認。変更は記録のみ。|
|2026-09-26|17:21:17 JST+0900|Codex|完了: 🛠 **エラー時対処**: Boolean/境界の失敗を点検し、失敗時は原因修正・再試験、なければ非発生を記録する。|物理的に根元が存在しない誤移動をbboxで通常FAILへ分類、Boolean計算自体のERRORは例外を維持。全11検査再成功。閾値変更なし。|
|2026-09-26|17:21:18 JST+0900|Codex|開始: - [ ] 🖐 **操作**: 設計範囲の候補を光学評価し結果JSONを保存する。|手順3:30..50°/0..30mm延長の光学探索をstudy.pyに実装して実行。変更範囲は新研究コードとreports、既存ファイルは保持。完了は探索全グリッドの幾何射影と対象可視率の記録。|
|2026-09-26|17:22:03 JST+0900|Codex|状況記録|40行動到達リセット。8/28通常項目完了。作業書review済み、爪延長11testsPASS。study.py searchで5040位置を解析・射影通過候補を実CAD両眼可視率評価中。session78354。現項目は未完了。|
|2026-09-26|17:23:02 JST+0900|Codex|ユーザー追記による一時中断: - [ ] 🖐 **操作**: 設計範囲の候補を光学評価し結果JSONを保存する。|ユーザーがPlaywright優先/API節約を前半とDoDへ追加指示。ローカル光学計算session78354はAPI不使用で続行、次のチェックを手順0へ切り替える。|
|2026-09-26|17:23:03 JST+0900|Codex|開始: - [ ] 🖐 **操作**: 専用headlessセッションと現在のOnshape画面を確認し、API-USAGE.mdに開始時のローカルカウンタとキャッシュ所在を記録する。|追加手順0:API不使用でheadlessタブとカウンタファイル/キャッシュ所在を確認。変更許可範囲はAPI-USAGE.mdとUI証拠。|
|2026-09-26|17:23:52 JST+0900|Codex|完了: 🖐 **操作**: 専用headlessセッションと現在のOnshape画面を確認し、API-USAGE.mdに開始時のローカルカウンタとキャッシュ所在を記録する。|headless true/tab0 CAD/tab1 manual。APIカウンタ526をローカル読取、今回直接API0。API-USAGE.mdに記録。公式Free年2500、ブラウザ通信は年次枠対象外と確認。|
|2026-09-26|17:23:54 JST+0900|Codex|開始: - [ ] 🔎 **確認**: 作成/取込/剛体/mate/検証/version/exportのUI操作経路とAPI例外の条件をAPI-USAGE.mdへ記載する。|UI操作経路とAPI例外条件を明文化。変更はAPI-USAGEとreview追記のみ。|
|2026-09-26|17:24:30 JST+0900|Codex|完了: 🔎 **確認**: 作成/取込/剛体/mate/検証/version/exportのUI操作経路とAPI例外の条件をAPI-USAGE.mdへ記載する。|API-USAGEに7処理のUI経路/確認/例外表。Mate/Versionは通常UI、exporterだけ標準UIにないため例外候補。review再実施PASS_WITH_NOTES。|
|2026-09-26|17:24:32 JST+0900|Codex|開始: - [ ] 🧪 **テスト**: 既存検証済みドキュメントで読み取り専用のDOM取得・画面保存を試し、認証済みCAD画面と安定したlocatorを確認する。|Playwright読取テスト。既存CADのDOMと画面を保存しlocator一意性を確認。既存モデルに変更しない。|
|2026-09-26|17:25:09 JST+0900|Codex|状況記録|追加ユーザー指示:画面からできない処理の整理とAPI極小化。APIゼロを第一目標、UI+ローカルURDF/pose STEP解析を先行。UI不存在/未確認/煩雑を台帳で分離。現時点API必須と確定した項目なし。|
|2026-09-26|17:26:08 JST+0900|Codex|状況記録|UI初回:12instance/13mateは読めるがsession timeout表示あり。外側genericクリックでは復旧せず、成功扱いにしない。DOMの実reconnect要素を特定して復旧を試す。直接APIは0のまま。|
|2026-09-26|17:27:00 JST+0900|Codex|状況記録|最新要求を後半手順6/DoD D7へ追加。urdf_from_stepをPixi+公式最新安定OCCTへ対応しUI出力STEPから変換。通常36項目。数値検証基準は維持、従来API exporterを既定から除外。|
|2026-09-26|17:28:04 JST+0900|Codex|完了: 🧪 **テスト**: 既存検証済みドキュメントで読み取り専用のDOM取得・画面保存を試し、認証済みCAD画面と安定したlocatorを確認する。|CAD DOM/スクリーンショットを保存して目視。base_link locator一意、12instance/13mate。実reconnectリンクの通常クリックでtimeout表示消失。API526のまま。|
|2026-09-26|17:28:05 JST+0900|Codex|開始: - [ ] 🛠 **エラー時対処**: セッション/locator失敗時は画面を再取得して修正し、繰返しAPIへ切替えず、未解決と復旧方法を記録する。|UI復旧のエラー経路を記録して前半ゲートを閉じる。APIへ切替えず一意locatorで復帰できたことを確認。|
|2026-09-26|17:28:06 JST+0900|Codex|完了: 🛠 **エラー時対処**: セッション/locator失敗時は画面を再取得して修正し、繰返しAPIへ切替えず、未解決と復旧方法を記録する。|外側メッセージclickでは接続復帰しない事例とanchor指定の解決をAPI-USAGEへ記録。未解決認証問題なし。手順0四項目完了、API直接呼出し0。|
|2026-09-26|17:28:07 JST+0900|Codex|開始: - [ ] 🖐 **操作**: 設計範囲の候補を光学評価し結果JSONを保存する。|中断した手順3光学探索を再開。バックグラウンド78354はAPIゼロで継続。search.jsonの全5040候補と最終shortlistを確認する。|
|2026-09-26|17:29:20 JST+0900|Codex|状況記録|光学探索途中:0/5mm延長では30..50°全不成立。10mmで40°、15mmで35°、20mmで30°が成立。20mm/30°の両眼最小可視率91.15..93.53%。15mm/30°の最大でも76.72%。マウント未追加の楽観的検査であり採用未決定。|
|2026-09-26|17:30:28 JST+0900|Codex|状況記録|追記後の整合レビュー:TR-4を手順0/5/6、TR-5を0/7/8へ更新。API exporter前提の旧文章を削除し、UI STEP→Pixi変換の順に統一。基準の縮小なし。|
|2026-09-26|17:31:26 JST+0900|Codex|完了: 🖐 **操作**: 設計範囲の候補を光学評価し結果JSONを保存する。|study.py search成功。5040グリッド/356両眼通過。6ターゲット描画ずつの最終候補、失敗早期打切りは明示。search.json/optical-shortlist.json。0/5mm不成立、最小pitch10mm40/15mm35/20..30mm30度。|
|2026-09-26|17:31:27 JST+0900|Codex|開始: - [ ] 🔎 **確認**: 成立候補の実マウント・質量・250g負荷・指の曲げ比を比較し採用SPECを保存する。|実マウント比較:各延長の最小傾斜でY/Z非劣候補をCAD化し、質量/250g/追加爪とパッド/干渉を比較する。採用SPECを保存するまで未完了。|
|2026-09-26|17:34:28 JST+0900|Codex|完了: 🔎 **確認**: 成立候補の実マウント・質量・250g負荷・指の曲げ比を比較し採用SPECを保存する。|33実マウント候補中31静的通過、2カメラ/台座干渉で棄却。E20_P30_Y165_Z235を本検証へ選定。高さ70.30mm、旧比-12.40mm。爪/パッド差分含む手首部分0.383540Nm/旧比+9.45%。SELECTION、SPEC、selection.json。|
|2026-09-26|17:34:29 JST+0900|Codex|開始: - [ ] 🧪 **テスト**: 採用候補を実形状で両眼/3対象/開閉姿勢を再評価する。|採用候補の実マウント込み光学再評価。両眼/3診断物と空の開中閉を保存。変更は検証scriptとimages/reportsのみ。全対象90%/75mmを同一条件で確認。|
|2026-09-26|17:37:16 JST+0900|Codex|完了: 🧪 **テスト**: 採用候補を実形状で両眼/3対象/開閉姿勢を再評価する。|実マウント/全保持部品入りで6対象眼ケースPASS。最小可視率93.2768%、最小軸距離78.685mm、848x480合格/720p100mm条件不合格。旧/新24画像を保存し対象が下寄りに入る実表示を確認。full-optics.json。|
|2026-09-26|17:37:17 JST+0900|Codex|開始: - [ ] 🛠 **エラー時対処**: 探索と実体の差を点検し、必要なら同じ条件で候補を再選定する。失敗候補は削除しない。|探索と実体の差を照合。実体化で失敗した低すぎる2候補を記録し、採用候補の光学基準変更がないことを確認する。|
|2026-09-26|17:37:19 JST+0900|Codex|完了: 🛠 **エラー時対処**: 探索と実体の差を点検し、必要なら同じ条件で候補を再選定する。失敗候補は削除しない。|採用候補はbare/full最小可視率が一致。実体化で落ちた2候補と交差体積を保存し棄却。採用候補を再選定する必要なし。720p不適合を維持し、画像では対象下寄りという構図も記録。|
|2026-09-26|17:37:20 JST+0900|Codex|開始: - [ ] 🖐 **操作**: 採用CADをSTEP/STLへ出力し再読込で部品同一性と変更マスクを確認する。|手順4 保存CAD再読込。STEPと造形4部品STL、比較レンダーを出力し、232保持部品と4局所変更の差分を検証。変更は新CAD/images/reportsとexport script。|
|2026-09-26|17:39:51 JST+0900|Codex|状況記録|40行動到達リセット。通常16/36完了、手順4操作進行中。5040光学/33実体比較から30度20mm延長を選定、実光学PASS。CAD再読込257occ/262body/232保存PASS、描画session61843処理中。直接API0、counter526。追加要求Pixi/最新OCCTは後半手順6とD7。|
|2026-09-26|17:40:06 JST+0900|Codex|完了: 🖐 **操作**: 採用CADをSTEP/STLへ出力し再読込で部品同一性と変更マスクを確認する。|export_cad.py exit0。STEP SHA b7ece605181c219434720dd24d32191afa48c2b2f16fa48cebe476a1a40d4b3a、257occ/262body、232保持。左右根元差分/4造形単一solid&水密STL/4穴probePASS。旧新同縮尺の側面/斜視画像を目視。|
|2026-09-26|17:40:07 JST+0900|Codex|開始: - [ ] 🔎 **確認**: 開閉/手首の干渉、ねじ挿入深さ、工具アクセスを再評価して既知/未知を保存する。|開閉25..135度5度刻み、手首2度刻み、実保存STEPのCAM5+指/パッド対保持部品を検査。ねじ挿入/工具経路も現位置で再計算し既知/未知を記録する。|
|2026-09-26|17:43:55 JST+0900|Codex|状況記録|開閉途中のraw非PASS8組は、旧/新共通のfinger対washer接触4組とbolt0.15mm隙間4組、材料交差0。一般隙間0.3mm検査と締結部適合を区別してSPEC追記。工具は仮定75mmshaft/40mm手領域/100mm引抜き、実係合は未知。|
|2026-09-26|17:46:50 JST+0900|Codex|状況記録|開閉23姿勢完了、各6100対象ペアで新規/増加欠陥0。8既存締結隙間はraw保持。工具12stagePASS、完成状態の台座4本は遮蔽されるため組立順をSERVICE.mdへ記録。手首openで変更部品[-180,102]deg、保持アーム制約と合成は全3状態後。|
|2026-09-26|17:49:14 JST+0900|Codex|完了: 🔎 **確認**: 開閉/手首の干渉、ねじ挿入深さ、工具アクセスを再評価して既知/未知を保存する。|保存STEP開閉23姿勢/各6100対象ペアで新規増加0、既存締結8ペアraw保持。手首open/mid/closed 2度刻み、合成物理範囲[-124,102]、Onshape/URDF[-102,124]。台座挿入2.5mm/底余裕1.5mm、D4053mm/余裕1mm、工具12段階PASS。geometry/service SHA一致。|
|2026-09-26|17:49:15 JST+0900|Codex|開始: - [ ] 🧪 **テスト**: 侵入・断絶・誤座標・Booleanエラーの対照を同じ判定器で検出する。|手順4不良対照:材料侵入、実カメラ誤移動、断絶/根元移動、非solid不明、Boolean例外がPASSにならないことを同じ判定器で検証。|
|2026-09-26|17:49:55 JST+0900|Codex|状況記録|負対照で検出器の不足を発見:同じペアの材料交差増加だけでなく、既存不足隙間0.2→0.05mmの悪化も検出すべき。先行test_gap_worsening_not_hiddenがRED。gap差分を追加して保存23姿勢にも再適用する。|
|2026-09-26|17:51:02 JST+0900|Codex|完了: 🧪 **テスト**: 侵入・断絶・誤座標・Booleanエラーの対照を同じ判定器で検出する。|18 tests PASS/21.26秒。侵入/包含/実カメラ誤配置/爪誤移動/断絶を拒否、surface UNKNOWN/Boolean ERRORを区別。既存gap悪化RED→GREEN。保存23姿勢にもgap差分を再適用し悪化なし。validation-tests.xml。|
|2026-09-26|17:51:03 JST+0900|Codex|開始: - [ ] 🛠 **エラー時対処**: 最終CADに新規禁止干渉がないか照合する。失敗なら設計を直し、旧検証結果を流用せず再評価する。|手順4最終レビュー:入力SHA、18controls、232保持、現物未知、可動域縮小、段取りと失敗候補の記録を照合して新規禁止干渉が残らないか確認する。|
|2026-09-26|17:51:05 JST+0900|Codex|完了: 🛠 **エラー時対処**: 最終CADに新規禁止干渉がないか照合する。失敗なら設計を直し、旧検証結果を流用せず再評価する。|幾何根拠をGEOMETRY/SPEC/SERVICEへ統合。新規禁止干渉なし、既存fit8組raw保持、物理[-124,102]/URDF[-102,124]を確定。工具の完成状態失敗と段取りPASSを分離。物理耐久性と全姿勢連続掃引は未確認。|
|2026-09-26|17:51:06 JST+0900|Codex|開始: - [ ] 🖐 **操作**: 新publicドキュメントへ採用CADを取り込み、12剛体と関節を構築する。|手順5 Onshape構築。API0目標でUIのコピー/更新と新規取込を調査し、旧版を保持した新public文書に今回STEPと12剛体/関節を成立させる。UI結果と保存状態を確認する。|
|2026-09-26|17:51:45 JST+0900|Codex|状況記録|公式Copy workspace/Import UpdateのUI経路を確認。改善版は検証済みcompactの独立コピーに今回STEPを更新して組立を継承・再検証する方針。以前のゼロから再構築と区別して記録。更新失敗時はUI新規取込に移るがAPIへ切替えない。|
|2026-09-26|17:56:37 JST+0900|Codex|状況記録|40行動リセット。通常20/36完了、手順5操作中。UI独立publicコピー29e8557c76e89bcf64f50566作成、12剛体13mate継承。新STEP反映は未実施。Part Studio Import 1の右クリックUpdateを発見。getByText exactはタブに一致せずsnapshot refで復旧、click rightは位置引数。API直接0、counter526。|
|2026-09-26|18:00:37 JST+0900|Codex|状況記録|UI更新で11カメラ部品が未所属となった。復旧中、run-codeの複数クリック完了を待たず次の編集を開始したため後続選択がcamera_bodyへ混在した。操作を止め完了を待ち、2グループの選択を実体名で再構築・所属数を検証する。以降はブラウザ変更を必ず1実行ずつ完了確認し、各クリック前に編集対象名をassertする。未完了維持。|
|2026-09-26|18:06:10 JST+0900|Codex|状況記録|40行動到達リセット。通常20/36完了、手順5操作継続。新PS2195f3c400eb079287ae06af、UI STEP更新済み。camera_bodyの誤所属を除去しBODY/PLUG/CABLE3部品だけで保存確認。camera_mountは9保持+carrier+washer0、残り7をUI再選択中。非同期修復中の別編集を禁止するguardを追加。API直接0。|
|2026-09-26|18:07:28 JST+0900|Codex|状況記録|手順5エラー対処に残っていた旧API成功表記をUIの成功表示へ訂正。要件/数値基準は不変。Import Updateで欠落するのは未対応ではなく通常UIで再選択可能な参照修復。Shift範囲選択は今回の編集中に追加反映されず、個別選択と選択済みDOM待機を採用。|
|2026-09-26|18:15:49 JST+0900|Codex|完了: 🖐 **操作**: 新publicドキュメントへ採用CADを取り込み、12剛体と関節を構築する。|UI独立public29e8557c76e89bcf64f50566へSTEP b7ece605更新。カメラ11部品参照修復後Parts0/Composite12、native Instances12/Mates13、エラー表示0。camera_body3部品を明示再選択。両camera connector=(-0.2,165,235)mm、wrist[-102,124]を保存後再表示確認。新PS/Motion名とlegacy静的タブを区別。直接API0。|
|2026-09-26|18:15:50 JST+0900|Codex|開始: - [ ] 🔎 **確認**: Onshape実姿勢11件と画面上のinterference/animationを確認・記録する。|手順5確認。新native assemblyの11代表姿勢とInterference/Animateを通常UIで検証しスクリーンショット/実表示角を記録する。変更範囲は新文書の姿勢と検証成果物。最終STEP変換との数値照合は次項と手順6で行う。|
|2026-09-26|18:16:29 JST+0900|Codex|状況記録|40行動リセット。通常21/36完了、手順5確認開始。Native12instance/13mateエラー表示0。手首上限は保存直後一時的に138表示だったが開き直すと124で保存済み。UIは保存後再表示で照合必須。公式のMate位置値をdoubleclickして数値移動する操作を確認、これから11姿勢のUI経路を試す。API直接0。|
|2026-09-26|18:24:18 JST+0900|Codex|状況記録|Named positionsの通常UIに5駆動関節列を追加。初回captureでyaw=-27.711degが残っていたため、全5値0のzeroを明示作成してApply、成功通知を確認。small_joint1_yaw=10degも保存/Apply/実表示移動確認。残り9ケースをrecord_poses.pyで直列実行中session89883。角度表の値とapplied通知はSTEP配置の数値証明とは別に記録する。|
|2026-09-26|18:26:38 JST+0900|Codex|状況記録|Named positions small_joint2_shoulderに保存[0,10,0,0,0]は成立するがApplyは Mates could not be solved を返した。20秒timeoutを成功扱いにせずrunを停止し診断画像を保存。0/小yawの成功と分離し、次は通常UI Animateの小刻み肩回転でsolverの可動性を切り分ける。|
|2026-09-26|18:32:47 JST+0900|Codex|状況記録|40行動到達。通常21/36、手順5確認進行中。UI named positionの肩10deg一括適用はsolver失敗。context Animate Single 0→10deg/101stepsは終点10degへ正常到達し画像保存。timeout中も3.465→6.733→10degと進んだため時間超過を機構失敗とは判定しない。実到達姿勢のUpdate named positionを実行中。直接API0。|
|2026-09-26|18:34:29 JST+0900|Codex|状況記録|Animate 0→10degは成功するが、閉じた後Update named positionすると全5角度0degを捕捉。アニメーション終点は保存姿勢ではない。現在姿勢に等しいzeroのcontext menuではApplyが表示されず、その待機timeoutを記録。shoulder rowを1degへ修正し小刻み適用を診断中。|
|2026-09-26|18:37:41 JST+0900|Codex|状況記録|肩1deg/2deg/3degのUI適用成功。連続scriptはrow rename保存と角度保存が競合し、3deg入力が2degへ戻りApply menuなしでtimeout。2秒安定待ちと保存値再読取を各編集・適用後に加え4→10deg再開。solver failureとUI保存競合を別分類する。|
|2026-09-26|18:40:24 JST+0900|Codex|状況記録|肩4..10degすべてUI is applied確認。最終0/10/0/0/0保存と画像を確認。native-ui-poses.jsonに失敗履歴を保持し3/11 UI姿勢取得。native数値はまだSTEP未検証。保存wait2s/保存値再読取/solver toast検出、currentのApply省略をtemplateへ反映し残8ケース開始。|
|2026-09-26|18:41:43 JST+0900|Codex|状況記録|40行動到達リセット。通常21/36、手順5確認継続。11pose中zero/yaw10/shoulder10/elbow10の4件UI適用済み、wrist10処理中(session73933)。肩は1deg補間成功、UI保存競合はwait+保存再読取で改善。API-USAGEへ観察・失敗・復旧を追記。直接API0、STEP数値検証とPixi/OCCTは後続未実施。|
|2026-09-26|18:44:38 JST+0900|Codex|状況記録|7/11 UI姿勢成功。wrist_upper +124deg一括適用でsolver失敗、失敗ログui-logs/wrist_upper.txt保存。increment_pose.pyで0→124degを10deg中間姿勢から段階適用中。各名称/角度の保存待ちと再読取を行い、最後に実STEP確認を残す。|
|2026-09-26|18:49:27 JST+0900|Codex|状況記録|wrist_upper: 10deg補間も20degでsolver失敗。Animate 0→124/25stepsは終点到達、開いたままUpdate menuは使えず。通常UI Apply limit position > Max Z angle limitで124へ移動しUpdate captureするとgripper -19.022deg漂移を検出。表のgripperだけ0へ修正→Applyは成功、0/0/0/124/0確認。実到達poseをUpdateで保存する方法を追加し再開。|
|2026-09-26|18:51:43 JST+0900|Codex|状況記録|UI gripper_open65degは成功。gripper_closed-45deg一括適用はsolver失敗したが、Apply limit position > Min Z angle limit→Updateで0/0/0/0/-45を捕捉成功。wrist124は実捕捉後も5値一致。残りrestored_midと干渉検出を継続。新helperは既存row再利用/全5値確認/Apply後Update capture/過去ログ保存を追加。|
|2026-09-26|18:53:00 JST+0900|Codex|状況記録|record_poses.py成功:11/11 UI姿勢。wrist124/open65/closed-45/restored0はApply後Update captureでも全5値一致。native-ui-poses.jsonのstatus=UI_APPLIED_NUMERICAL_CHECK_PENDING。STEP数値照合は未実施で明示。中立で12instanceのInterference detection画面を開始。|
|2026-09-26|18:53:42 JST+0900|Codex|状況記録|40行動到達。通常21/36、手順5確認。11/11 UI姿勢適用/復帰成功、native STEP数値は未検証。中立Interferenceで12instance選択をdialog列挙確認、6件(wrist/camera_mount4、camera_body/camera_mount2)、standard content/top levelともfalse。各ハイライトの箇所を確認中。API直接0。|
|2026-09-26|18:55:38 JST+0900|Codex|完了: 🔎 **確認**: Onshape実姿勢11件と画面上のinterference/animationを確認・記録する。|11/11 UI姿勢適用/復帰、肩0→10とwrist0→124 Animate終点確認。中立12instances干渉6件を個別ハイライト目視(台座4/D4052ねじ係合位置)、6画像/rounded bboxを保存。native-ui-poses/native-interference/NATIVE-VALIDATION。STEP独立数値確認は次項。|
|2026-09-26|18:55:39 JST+0900|Codex|開始: - [ ] 🧪 **テスト**: 最終versionと11代表姿勢からUIでSTEP/必要なメッシュを保存し、部品名・配置・単位をローカルで解析できることを確認する。|手順5テスト:最終versionをUI作成し11姿勢のSTEPをUI出力、名前/配置/単位を解析。変更許可は新文書version/pose、outputs/CAD/native-poses、解析script/reports。完了条件は実ファイルとXCAF配置/単位の取得、APIは使わない。|
|2026-09-26|18:57:30 JST+0900|Codex|状況記録|公式Exporting Files(2026-09-24更新)と実FreeアカウントのAssembly ExportでURDF選択を確認。Geometry STL/GLTF/GLB/OBJあり。onshape-urdf-ui-option.png、API-USAGEのUI不存在候補を機能ありへ訂正。今回STEP経路に加え標準UI URDFを比較用保存する(指定Pixi変換器は省略しない)。|
|2026-09-26|19:02:48 JST+0900|Codex|状況記録|UI版4577cc931e9bc290e2b31032作成/URL確認。版からzero STEP AP242/mm/None/Z-up/hidden含むをダウンロード成功。10,592,591bytes、262parts/207solid/55sheet、全配置ほぼI(max2.22e-16)、名前保持、composite階層はflat。標準UI URDF zipもDL成功:19links/18joints/261STL。まだ生成内容/FK未検証。|
|2026-09-26|19:05:19 JST+0900|Codex|状況記録|40行動到達。通常22/36、手順5テスト進行中。V1/zero STEP/native UI URDF取得済み。zeroは元採用CADと全名称/solid-sheet数一致、bbox差最大1.23e-6mm。ただし既存肩部品の既定積分体積差5.574mm3があるため高精度積分で診断中、形状完全一致とは未判定。version内でyaw10のApply可能、exportが表示姿勢を保持するかpilotを検証中。直接API0。|
|2026-09-26|19:09:20 JST+0900|Codex|状況記録|version内yaw10表示→STEPは全行列Iで失敗(10,592,591bytes)。誤姿勢fileをdiagnostics/version-yaw10-exported-zero.stepへ保持しmanifest rejected記録。Mainへ復帰、Named positions paneが閉じたため最初Missing row失敗、paneを開く前提待ちを修正。形状診断はCQ.tessellateがrelative deflectionであることとCAM5_D405_CARRIER実名を確認し、絶対0.001mm meshへ修正して再試験中。|
|2026-09-26|19:12:12 JST+0900|Codex|状況記録|Main yaw10 STEPは262部品、base I/肩以降Rz(-10deg)を取得。version失敗例はSTEP DATA全体がzeroと同一、bbox差0と確認。11ファイル連続UI export/読取を開始。追加7部品のmesh診断完了:変更4部品のサンプル距離最大1.63e-9mm、既存3部品は最大0.03755mmでmesher報告deflection自体最大0.06252mm、高精度体積差も残る。新しい合格閾値を設けずraw保持し、全BRep同一とは主張しない。|
|2026-09-26|19:21:13 JST+0900|Codex|完了: 🧪 **テスト**: 最終versionと11代表姿勢からUIでSTEP/必要なメッシュを保存し、部品名・配置・単位をローカルで解析できることを確認する。|11 UI STEP取得/XCAF読込完了。262部品/207solid/55sheet/mm。12剛体×11=132配置抽出、所属部品行列差0、ローカルbbox差0、5角度最大誤差0.000003058deg。固定版zeroとMain10姿勢。誤ったversion yawは隔離。EXPORT/NATIVE-VALIDATION更新、API0。|
|2026-09-26|19:21:14 JST+0900|Codex|開始: - [ ] 🛠 **エラー時対処**: UIの成功表示と実姿勢を照合する。角度不一致なら中間姿勢経由で再試験し、認証/サービス障害は記録して復旧を試す。|手順5エラー対処:失敗履歴と全11輸出姿勢を照合。UI通知/実配置の違い、固定版出力失敗とMain回復を確認し、基準を変えず復旧済みか判定する。変更は記録のみ。|
|2026-09-26|19:21:29 JST+0900|Codex|状況記録|訂正:直前の記録の所属部品行列差0は集計前の誤記。最大member translation差32.907961mmを検出したため全所属一致という文書表現を撤回し、手順5エラー対処で原因調査を開始する。262件取得と角度逆算自体は完了、数値一致判定は保留。|
|2026-09-26|19:24:45 JST+0900|Codex|状況記録|40行動リセット。通常23/36、手順5エラー対処中。全11 UI STEP/XCAF取得完了、角度最大差3.058e-6deg。ただし左右pad逆所属をopenの部品行列32.908mm差で検出。jaw_l unionを解除して正しい12部品をUI再選択中session95296。他UI変更は完了まで実行しない。V1は修復前として保持、修復後version/STEP再取得予定。API0。|
|2026-09-26|19:28:41 JST+0900|Codex|状況記録|jaw_lを旧unionから明示12部品へ再構築し保存。jaw_rは旧unionが左padと重複し Cannot create a closed composite part that partially overlaps another composite part を表示。旧union解除後、右12部品を明示再選択中session。V1全11STEPとFAILレポートをdiagnostics/v1-pad-misassignedへ移し証跡保持。|
|2026-09-26|19:40:34 JST+0900|Codex|状況記録|40行動リセット。手順5エラー対処:左右jaw各12部品を通常UIで再指定、Parts0/Composite12、Assembly12/13を復旧。修復後11STEP再取得/再読込が完了、small gripperでpad/finger配置一致確認。これから全剛体整合とV2保存。直接API0、counter526。|
|2026-09-26|19:43:16 JST+0900|Codex|完了: 🛠 **エラー時対処**: UIの成功表示と実姿勢を照合する。角度不一致なら中間姿勢経由で再試験し、認証/サービス障害は記録して復旧を試す。|V1のpad逆所属を通常UIで修復、全11STEP再取得。132群の内部行列差0、角度最大誤差3.058e-6deg、22jaw検査PASS。V2 f6162b4adc88af9d07f1194a保存、final-version.step SHA9f58c947、restored_midとDATA完全一致。出力path置換ミスはSHA一致downloadキャッシュ復元で解決。誤ファイル/失敗履歴保持、API0。|
|2026-09-26|19:43:17 JST+0900|Codex|開始: - [ ] 🖐 **操作**: urdf_from_stepの既存状態と公式OCCT最新安定版を調査し、変換器用の追跡可能なPixi実装計画/入力契約を保存する。|手順6操作:ユーザー所有urdf_from_stepを調査し、公式OCCT最新安定版、Pixi入力/出力/関節契約、変更とテスト計画を保存。変更範囲は変換器用隔離checkoutとCONVERTER文書。まず既存差分/指示/現在のbuildを確認する。|
|2026-09-26|19:45:18 JST+0900|Codex|完了: 🖐 **操作**: urdf_from_stepの既存状態と公式OCCT最新安定版を調査し、変換器用の追跡可能なPixi実装計画/入力契約を保存する。|urdf_from_step ebe40d9を新規clone/clean確認、codex/pixi-occt8作成。公式OCCT latest8.0.1/b8f597c、conda linux-64 pythonocc8.0.1あり、Pixi0.79既存。ROS依存/旧import/名前符号化入力を調査。CONVERTER.mdへPixi lock、互換reader、単独CLI/明示設定、全occurrence保全、441/11検証計画を記録。|
|2026-09-26|19:45:19 JST+0900|Codex|開始: - [ ] 🔎 **確認**: Pixi manifest/lock/tasksと必要なOCCT互換修正を実装し、その固定版が実際にビルド・実行されることを確認する。|手順6確認:Pixi manifest/lock/tasks、OCCT8互換readerとROS不要CLIを実装しwheel buildと実行版確認。変更はurdf_from_stepブランチと変換記録。最新安定8.0.1の実runtimeを使う。|
|2026-09-26|19:51:27 JST+0900|Codex|完了: 🔎 **確認**: Pixi manifest/lock/tasksと必要なOCCT互換修正を実装し、その固定版が実際にビルド・実行されることを確認する。|Pixi manifest/lock/tasks実装・install成功。Python3.12.14/pythonocc8.0.1/OCCT8.0.1実ロードlibTKernelを確認。ROS不要CLI/全occurrence保持reader/明示設定/legacy draft追加、旧reader互換入口維持。wheel build/install/site-packages実行/compileall成功。ruff新モジュール整形、build/runtimeログ保存。|
|2026-09-26|19:51:29 JST+0900|Codex|開始: - [ ] 🧪 **テスト**: 小STEPの回帰と今回の最終UI出力STEP→URDF変換を実行し、441閉路/11ネイティブ姿勢の一致を検証する。|手順6テスト:小STEPの実読込/名前/反復入れ子配置/mm-inches/複数solid/不正入力回帰、V2実STEPから12新meshとURDF生成、441閉路/11native姿勢を既存閾値で検証。変更はconverter tests/不具合修正/robot設定と出力/検証記録。|
|2026-09-26|19:57:08 JST+0900|Codex|状況記録|ユーザーのcommit & push指示により途中保存を実施。26/36、step6テストは継続中。小STEP13PASS、V2の262 occurrence読取成功、ruff/再wheelビルドPASS。manifest指定だけではcwdが変わらないため最初のruff対象pathが不在となり、converter cwdで再実行して解消。最終URDF/441/11 FK/マニュアルは未完了。|
|2026-09-26|19:58:02 JST+0900|Codex|状況記録|変換器checkpoint commit 1b2cea3、codex/pixi-occt8。git diff --cached --checkがpixi.toml末尾空行を検出し修正。限定15ファイル、秘密パターンscan PASS。設計側も途中保存を継続。|
|2026-09-26|19:58:26 JST+0900|Codex|状況記録|40行動の状況: converter 1b2cea3 push成功。設計archive264ファイル325428896 bytes scan PASS。gitignoreによりoutputsが通常addでは省略されるため限定出力pathを明示的に追加する。26/36、step6検証継続。|
|2026-09-26|20:00:23 JST+0900|Codex|状況記録|途中保存push確認: gripper 6117edb / codex/onshape-low-profile-d405、converter 1b2cea3 / codex/pixi-occt8。267ファイル設計snapshot。STEP/STL binaryと元pytest失敗XMLの空白保存を属性で限定。step6検証へ復帰しV2→新メッシュ/URDF生成を実行中。|
|2026-09-26|20:01:37 JST+0900|Codex|完了: 🧪 **テスト**: 小STEPの回帰と今回の最終UI出力STEP→URDF変換を実行し、441閉路/11ネイティブ姿勢の一致を検証する。|OCCT8.0.1/PixiでV2 STEP SHA9f58c947から262 occurrence全所属、16links/15joints/12新STL生成。小STEP13PASS、441閉路最大3.47e-17m、11native FK並進8.78e-9m/回転5.34e-8rad、4負対照試験PASS。1000倍単位対照はyawの並進0では無効で肩poseに修正、初回red保持。robot/model、robot/validation.json、reports/robot-negative-tests.xml。|
|2026-09-26|20:01:38 JST+0900|Codex|開始: - [ ] 🛠 **エラー時対処**: ビルド/変換の失敗を修正し、使用したOCCT版・設定・制約・再現コマンド・変換器差分の保存先を記録する。|step6エラー記録: CONVERTER/robot READMEへOCCT色binding修正、設定/再現方法/制約/commit保存先を記載する。検証結果をproject/native記録へ反映。範囲outputs/low-profile-250g、完了条件はコマンドと証跡が追えること。|
|2026-09-26|20:02:12 JST+0900|Codex|完了: 🛠 **エラー時対処**: ビルド/変換の失敗を修正し、使用したOCCT版・設定・制約・再現コマンド・変換器差分の保存先を記録する。|CONVERTER.md/robot READMEにOCCT8.0.1実行版、1b2cea3保存先、Pixi/変換/検証コマンド、設定根拠、旧reader色binding修正と負対照fixture修正を記載。441/11PASS、動力学/材料/ROS/実機未検証を分離。project状態も実検証済みに更新。|
|2026-09-26|20:02:22 JST+0900|Codex|開始: - [ ] 🖐 **操作**: 実画面付きMANUALと比較REPORTを生成する。|step7操作: MANUAL/REPORT/HTML/PDFと実画面画像参照を作成。範囲outputs/low-profile-250gおよびwork/low-profile/build_manual.py。各手順の操作箇所・入力・確認・失敗時対処、低さと負荷の比較、物理的未知が読めることを完了条件とする。|
|2026-09-26|20:07:29 JST+0900|Codex|完了: 🖐 **操作**: 実画面付きMANUALと比較REPORTを生成する。|MANUAL.md/HTML/PDFを20節で生成、実UI画面とCAD/両眼画像19枚を埋込。REPORTで30°/+20mm/-12.40mm/+9.45%/18°可動減を併記。V2 loading画像を再撮影し12instance/13mate/固定版を確認。API-USAGEとnative最終結果も追記。|
|2026-09-26|20:07:29 JST+0900|Codex|開始: - [ ] 🔎 **確認**: 文書と画像を目視し、参考30°、採用角、爪延長、荷重差、物理的未知を照合する。|step7確認: 20ページPDF/HTMLの画像表示・収まり・手順の実証拠と比較数値を目視照合。レビュー対象MANUAL/REPORT/WORKDOC、必要なら同範囲の誤記を修正しreview記録を残す。|
|2026-09-26|20:09:08 JST+0900|Codex|完了: 🔎 **確認**: 文書と画像を目視し、参考30°、採用角、爪延長、荷重差、物理的未知を照合する。|review-rubricでWORKDOC/MANUAL/REPORTを照合、final-review.md PASS_WITH_NOTES。HTML20節/19画像/拡大UI、印刷はみ出し0、PDF20ページ、13/17ページ目視、30°/20mm/9.45%/441/API0をPDF textでも照合。PyMuPDF不在・bundled runtimeなしのため既存popplerで検査。|
|2026-09-26|20:09:08 JST+0900|Codex|開始: - [ ] 🧪 **テスト**: 追加コードpytest/ruff、成果物参照、秘密情報、git diff --checkを検査する。|step7テスト: 追加Pythonのruff/format、CAD18/変換器13/FK4試験、成果物links/原入力hash/private除外を検査。範囲新コードと新成果物。失敗は記録し当該箇所のみ修正。|
|2026-09-26|20:11:04 JST+0900|Codex|状況記録|ユーザー追記: skillsのcommit漏れ防止。手順8とD4へ設計リポジトリ直下skills/にOnshape+write/review/startと参照ファイルを保存し、全件Git追跡/remote照合する条件を追記。CAD18とconverter/FK17の計35試験PASS、ruff初回36件はimport/整形修正で解消。|
|2026-09-26|20:12:02 JST+0900|Codex|状況記録|品質初回は低cost元repoの無関係な未追跡HN11 idler 4ファイルでFAIL。追跡変更はなし。本作業は触れず保存対象から除外。作業範囲保存の要件を、他作業も含め全repo clean要求に誤拡大した検査を修正し、外部未追跡一覧を明示。初回FAIL JSON保持。35試験PASS、秘密実値/パターン/ZIP scan PASS、API526不変。|
|2026-09-26|20:12:13 JST+0900|Codex|状況記録|40行動リセット: 通常30/36完了、手順7品質検査進行中。20ページ19画像の人向けマニュアル完成、35試験/441閉路/11native照合PASS、2repo checkpoint push済。残りは最終品質確認、skills/全件保存、最終commit/push、D1〜7の逐次照合。外部HN11作業は保持。|
|2026-09-26|20:12:40 JST+0900|Codex|完了: 🧪 **テスト**: 追加コードpytest/ruff、成果物参照、秘密情報、git diff --checkを検査する。|final-quality.json 13項目PASS。CAD18+converter/FK17=35試験PASS、ruff31ファイル/format PASS、リンク/STEP SHA/20p PDF/秘密実値とZIP/権限/git text diff-check PASS。元repo追跡内容保持、無関係HN11未追跡4件は除外して明記。|
|2026-09-26|20:12:40 JST+0900|Codex|開始: - [ ] 🛠 **エラー時対処**: 品質ゲートの不備を修正して再確認する。修正が不要なら非発生を記録する。|step7エラー対処: 初回lint36件と元repo clean誤判定の修正・再検査結果を整理。型/数値閾値の緩和や不良対照の削除をしていないことを確認し記録する。|
|2026-09-26|20:12:43 JST+0900|Codex|完了: 🛠 **エラー時対処**: 品質ゲートの不備を修正して再確認する。修正が不要なら非発生を記録する。|初回ruff/formatと元repo過剰clean判定の修正・再確認をfinal-reviewへ追記。final-quality-initial.json/ruff-initial.txtを保持。35試験と13品質項目PASS、数値閾値不変、幾何/物理の既知FAIL/UNKNOWNも保持。|
|2026-09-26|20:13:49 JST+0900|Codex|開始: - [ ] 🖐 **操作**: onshape-robot-workflowへ今回確認したfindings/tipsを追記し、成果物とリポジトリ直下skills/へ参照ファイル込みでコピーする。write/review/startの使用スキルもskills/に保存する。|step8スキル: onshape-robot-workflowをUI優先、全部品所属、Main姿勢STEP、Pixi/OCCT検証の実証知見で更新。local skillと設計repo skills/および成果物skills/が対象。write-workdoc-uv/review-written-workdoc/start-work-with-docsも参照込みで保存し出典とSHAを残す。|
|2026-09-26|20:14:22 JST+0900|Codex|完了: 🖐 **操作**: onshape-robot-workflowへ今回確認したfindings/tipsを追記し、成果物とリポジトリ直下skills/へ参照ファイル込みでコピーする。write/review/startの使用スキルもskills/に保存する。|Onshape SKILLと既存2参照をUI優先へ更新、ui-first-step-pixi.mdを追加。設計repo直下skills/とoutputs/skills/へOnshape/write/review/startの4スキル13ソースファイル、references/agents込みで同一SHAコピー。出典とmanifest、案内を作成。|
|2026-09-26|20:15:16 JST+0900|Codex|開始: - [ ] 🔎 **確認**: 新コード・新成果物をGit作業先studies/low-profile-20260926へコピーし、skills/の保存内容も含めSHA256と秘密情報除外を照合する。|step8保存照合: 新成果物/コードをstudies/low-profile-20260926へ同期し、repo skills/13ソース+案内+manifestとのSHA一致、秘密除外、元repo保持を確認。保存対象以外は変更しない。|
|2026-09-26|20:16:35 JST+0900|Codex|完了: 🔎 **確認**: 新コード・新成果物をGit作業先studies/low-profile-20260926へコピーし、skills/の保存内容も含めSHA256と秘密情報除外を照合する。|snapshot327ファイルのsource/保存先SHA一致、4スキル13ソースのglobal/output/repo SHA一致、ZIP含む秘密パターンPASS。既存write/review/start計8ファイルは既にGit追跡済みで同内容のためstatusに出なかった。ignoreとの直前推測を訂正。Onshape5ファイルと案内/manifestを新規追加対象にする。|
|2026-09-26|20:16:36 JST+0900|Codex|開始: - [ ] 🧪 **テスト**: 限定pathspecでステージしgit diff --cached --checkと変更一覧を確認する。|step8ステージ: 検査済みstudies/low-profile-20260926と4スキルの限定pathspecだけ追加。Git index全ファイル内容/SHAとmanifestを照合し、git diff --cached --checkを通す。既存他スキル/元repo未追跡は対象外。|
|2026-09-26|20:17:15 JST+0900|Codex|完了: 🧪 **テスト**: 限定pathspecでステージしgit diff --cached --checkと変更一覧を確認する。|限定102差分をステージ。snapshot327件と全skills13ソース+案内/manifestのindex内容/SHA一致、git diff --cached --check PASS。新規Onshape5ファイル、既存write/review/start8ファイルすべて追跡済み。|
|2026-09-26|20:17:15 JST+0900|Codex|開始: - [ ] 🛠 **エラー時対処**: 検査済み差分をcommit/pushする。拒否時は原因を記録し、force pushせず解決する。|step8最終push: 設計成果物/スキルの検査済み差分をcommitしてoriginへpush。converter1b2cea3は既にpush済。remote HEADとskills追跡内容を確認し、forceは使わない。|
|2026-09-26|20:18:01 JST+0900|Codex|完了: 🛠 **エラー時対処**: 検査済み差分をcommit/pushする。拒否時は原因を記録し、force pushせず解決する。|成果物/skills commit 00bd70c4e995788298d98e9de78f0e5e6d70ca35をorigin/codex/onshape-low-profile-d405へpush成功。converter 1b2cea31c56b875bf98c1d65084781322f5fc835もremote同値。force不使用、拒否なし。通常36項目完了。|
|2026-09-26|20:18:21 JST+0900|Codex|開始: - [ ] D1: TR-1,2の入力根拠、比較範囲、失敗候補、採用の理由が揃い、低さ/傾斜の改善と延長量を数値で示す。|D1照合: 参考commit/入力SHA、5040→356→33候補、棄却例と採用理由、30°/+20mm/-12.40mmをRESEARCH/SELECTION/REPORTの実体で確認する。変更は作業記録のみ。|
|2026-09-26|20:18:23 JST+0900|Codex|完了: D1: TR-1,2の入力根拠、比較範囲、失敗候補、採用の理由が揃い、低さ/傾斜の改善と延長量を数値で示す。|D1 PASS: RESEARCHの参考commit305ad0f/入力SHA、SELECTIONの5040→356→33（実JSON33件）、FAIL2候補、30°を満たす最小20mm延長と同群内最低高さ12.40mm改善を確認。大域最適とは主張しない。|
|2026-09-26|20:18:39 JST+0900|Codex|開始: - [ ] D2: TR-3の保存CAD、両眼視野、250g部分モーメント、局所根元保存、干渉と負の対照の証拠が揃い、未知をPASSへ変えていない。|D2照合: 保存CADのSHAと幾何/視野/工具レポート、250gモーメント差、18試験、physical未承認と720p不合格を照合する。変更は作業記録のみ。|
|2026-09-26|20:18:42 JST+0900|Codex|完了: D2: TR-3の保存CAD、両眼視野、250g部分モーメント、局所根元保存、干渉と負の対照の証拠が揃い、未知をPASSへ変えていない。|D2 PASS: 保存CAD hashとgeometry/service一致、23姿勢の新規悪化なし、両眼可視率93.28%/最短78.685mm、段階工具PASS。720p FAIL/完成時台座アクセスFAIL/physical承認false維持。250g部分モーメント+9.45%、根元保存と232保持/4局所変更、CAD18負対照試験も記録済。|
|2026-09-26|20:18:57 JST+0900|Codex|開始: - [ ] D3: TR-4のpublic Onshape version、実姿勢検証、新規URDFと441閉路/11姿勢の照合が揃う。|D3照合: public V2 ID、UI最終STEP SHA、新URDF実体と12メッシュ、441閉路/11native姿勢の閾値を確認する。|
|2026-09-26|20:19:00 JST+0900|Codex|完了: D3: TR-4のpublic Onshape version、実姿勢検証、新規URDFと441閉路/11姿勢の照合が揃う。|D3 PASS: public V2 f6162b4...、入力STEP SHA9f58c947一致、16/15 URDF実体と12新mesh SHA一致。441閉路3.47e-17m、11native並進8.78e-9m/回転5.34e-8radで既定閾値内。旧V1を最終として流用していない。|
|2026-09-26|20:19:14 JST+0900|Codex|開始: - [ ] D4: TR-5のスクリーンショット付き人用マニュアル、findings/tips、スキル更新、実体成果物があり、実物耐久性/造形/校正の未確認を明示する。リポジトリ直下skills/の本体/参照ファイル全件がGit追跡・push済みである。|D4照合: 人用20p/19画像、findings/未知の明記、skills本体13ファイルと全参照のremote追跡内容をSHAで確認する。|
|2026-09-26|20:19:34 JST+0900|Codex|完了: D4: TR-5のスクリーンショット付き人用マニュアル、findings/tips、スキル更新、実体成果物があり、実物耐久性/造形/校正の未確認を明示する。リポジトリ直下skills/の本体/参照ファイル全件がGit追跡・push済みである。|D4 PASS: remote保存commit00bd70cのskills/全13ソースをgit showしmanifest SHA全一致。本体/references/agents全件push済。20p/19画像/HTML拡大、findingsと実材料/定格未確定・深度未検証・製作未承認を確認。初回機械照合は同義表現ではなく未確認の一語を要求したため失敗、実際の明示文を照合して解消。|
|2026-09-26|20:20:13 JST+0900|Codex|状況記録|ユーザー追記: リポジトリ直下diary/にも作業書をcommit/pushする。最終DoD照合後のWORKDOC全記録とfinal-reviewをdiary/workdoc_Sep26-2026_low_profile_d405.mdおよびreview_Sep26-2026_low_profile_d405.mdへ同期し、追跡/remote保存を確認する。|
|2026-09-26|20:20:15 JST+0900|Codex|開始: - [ ] D5: 通常36項目が完了し、review後の作業書・最終品質検査・commit/pushの保存先を照合する。|D5照合: 通常36項目完了、review後文書と35試験/13品質項目、成果物commit00bd70cと変換器1b2cea3のremote一致を確認する。diary最終写しはD7後に完了記録とともにpushする。|
|2026-09-26|20:20:18 JST+0900|Codex|完了: D5: 通常36項目が完了し、review後の作業書・最終品質検査・commit/pushの保存先を照合する。|D5 PASS: 通常36/36、review-rubric後文書、35試験と13品質項目PASS、成果物00bd70c/変換器1b2cea3保存済みを照合。最新ユーザーのdiary追加保存は全DoD照合後の完了記録commitへ含める。|
|2026-09-26|20:20:43 JST+0900|Codex|状況記録|ユーザーが続きを別エージェントへ委譲する指示。実作業の続行を停止し、現在点の引き継ぎ保存へ切替。通常36/36、DoD D1〜D5完了、D6/API最終監査とD7/Pixi変換器最終照合は未チェックのまま引き継ぐ。以降はdiary作業書/レビュー/HANDOFFと完了時点の保存だけを行いcommit/pushする。|
|2026-09-26|20:23:51 JST+0900|Codex|状況記録|引き継ぎ文書を作成。D6/D7未実施、Onshape V2/両repo/ブラウザ3tab/再現コマンド/35試験/441/11/既知FAILとUNKNOWN/再実行禁止スクリプト/認証除外/外部HN11作業を記載。diaryに正本の全記録とreviewを保存する。旧snapshotのactive/suspended制御JSONは実記録ではないため保存コピーのみ除外し、履歴はWORKDOCと旧commitに保持。|
|2026-09-26|20:33:50 JST+0900|Codex|開始: - [ ] D6: UIで実施したOnshape操作と確認証跡、直接APIを使った例外/理由/呼び出し数、キャッシュ再利用をAPI-USAGE.mdへ記録し、不要なAPIポーリング/探索反復をしていない。|再開D6: 保存証跡の監査。元counter/profileは別PCのため現在値を確認したとはしない。|
|2026-09-26|20:33:50 JST+0900|Codex|完了: D6: UIで実施したOnshape操作と確認証跡、直接APIを使った例外/理由/呼び出し数、キャッシュ再利用をAPI-USAGE.mdへ記録し、不要なAPIポーリング/探索反復をしていない。|2026-09-26引き継ぎ再開監査: D6 PASS_ARCHIVED_EVIDENCE。API-USAGEと35 UIログ、final-quality、描画済みV2画像、公式API制限を照合。低配置スタディAPI0/例外なし/counter526不変は保存記録に基づく。今回Onshape API/UI操作0。詳細revalidation/handoff-audit.json。|
|2026-09-26|20:33:51 JST+0900|Codex|開始: - [ ] D7: urdf_from_stepがPixi環境と公式OCCT最新安定版で実際に動き、Onshape UI出力の今回STEPを入力にURDFを生成する。版/lock/実行ログ/回帰/関節設定/保存先が揃う。|再開D7: 指定converter commitとremote lock、公式OCCT latest、保存runtime/wheelログ/回帰/URDFの由来を照合する。新環境でのOCCT8実行ではない。|
|2026-09-26|20:33:53 JST+0900|Codex|完了: D7: urdf_from_stepがPixi環境と公式OCCT最新安定版で実際に動き、Onshape UI出力の今回STEPを入力にURDFを生成する。版/lock/実行ログ/回帰/関節設定/保存先が揃う。|D7 PASS_ARCHIVED_EVIDENCE。converter1b2cea3とremote pixi.lockをGitHub connectorで確認、公式latestはV8.0.1/b8f597c。保存runtime libTKernel.so.8.0.1、wheelビルド成功/installed intake、13小STEP+4FK+18CADのXML、V2入力SHA・12mesh SHA・441/11を照合。現環境はPixi/pythonocc不在、外部DNS不可のためOCCT8再ビルド/再変換は未実施。今回は独立の保存モデル再検証を別作業書で実施。|

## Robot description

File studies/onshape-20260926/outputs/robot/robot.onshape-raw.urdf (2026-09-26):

<?xml version="1.0" ?>
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
<robot name="low_cost_xl430_pg3_d405">
  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
  <link name="base_link">
    <inertial>
      <origin xyz="0 0 0" rpy="0 0 0"/>
      <mass value="0"/>
      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
    </inertial>
    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
  </link>
  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
  <link name="shoulder_yaw">
    <inertial>
      <origin xyz="0 0 0" rpy="0 0 0"/>
      <mass value="0"/>
      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
    </inertial>
    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
  </link>
  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
  <link name="upper_arm">
    <inertial>
      <origin xyz="0 0 0" rpy="0 0 0"/>
      <mass value="0"/>
      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
    </inertial>
    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
  </link>
  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
  <link name="forearm">
    <inertial>
      <origin xyz="0 0 0" rpy="0 0 0"/>
      <mass value="0"/>
      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
    </inertial>
    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
  </link>
  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
  <link name="wrist">
    <inertial>
      <origin xyz="0 0 0" rpy="0 0 0"/>
      <mass value="0"/>
      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
    </inertial>
    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
  </link>
  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
  <link name="gripper_crank">
    <inertial>
      <origin xyz="0 0 0" rpy="0 0 0"/>
      <mass value="0"/>
      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
    </inertial>
    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
  </link>
  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
  <link name="coupler_l">
    <inertial>
      <origin xyz="0 0 0" rpy="0 0 0"/>
      <mass value="0"/>
      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
    </inertial>
    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
  </link>
  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
  <link name="closing_left_1">
    <origin xyz="0 0 0" rpy="0 -0 0"/>
    <inertial>
      <origin xyz="0 0 0" rpy="0 0 0"/>
      <mass value="0"/>
      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
    </inertial>
  </link>
  <joint name="closing_left_1_frame" type="fixed">
    <origin xyz="-0.0194936 -0.014 -0.028" rpy="-3.14159 -0 -0"/>
    <parent link="coupler_l"/>
    <child link="closing_left_1"/>
    <axis xyz="0 0 0"/>
  </joint>
  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
  <joint name="coupler_left" type="revolute">
    <origin xyz="-0 0.014 -0" rpy="-0 -0 -0"/>
    <parent link="gripper_crank"/>
    <child link="coupler_l"/>
    <axis xyz="0 0 1"/>
    <limit effort="0" velocity="0" lower="-3.141592653589793" upper="3.141592653589793"/>
  </joint>
  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
  <link name="coupler_r">
    <inertial>
      <origin xyz="0 0 0" rpy="0 0 0"/>
      <mass value="0"/>
      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
    </inertial>
    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
  </link>
  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
  <link name="closing_right_1">
    <origin xyz="0 0 0" rpy="0 -0 0"/>
    <inertial>
      <origin xyz="0 0 0" rpy="0 0 0"/>
      <mass value="0"/>
      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
    </inertial>
  </link>
  <joint name="closing_right_1_frame" type="fixed">
    <origin xyz="0.0194936 0.014 -0.028" rpy="-3.14159 -0 0"/>
    <parent link="coupler_r"/>
    <child link="closing_right_1"/>
    <axis xyz="0 0 0"/>
  </joint>
  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
  <joint name="coupler_right" type="revolute">
    <origin xyz="0 -0.014 0" rpy="-0 -0 -0"/>
    <parent link="gripper_crank"/>
    <child link="coupler_r"/>
    <axis xyz="0 0 1"/>
    <limit effort="0" velocity="0" lower="-3.141592653589793" upper="3.141592653589793"/>
  </joint>
  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
  <joint name="gripper_drive" type="revolute">
    <origin xyz="0 -0.06 -0" rpy="-1.5708 1.5708 0"/>
    <parent link="wrist"/>
    <child link="gripper_crank"/>
    <axis xyz="0 0 1"/>
    <limit effort="0" velocity="0" lower="-0.785398" upper="1.13446"/>
  </joint>
  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
  <link name="jaw_l">
    <inertial>
      <origin xyz="0 0 0" rpy="0 0 0"/>
      <mass value="0"/>
      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
    </inertial>
    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
  </link>
  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
  <link name="closing_left_2">
    <origin xyz="0 0 0" rpy="0 -0 0"/>
    <inertial>
      <origin xyz="0 0 0" rpy="0 0 0"/>
      <mass value="0"/>
      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
    </inertial>
  </link>
  <joint name="closing_left_2_frame" type="fixed">
    <origin xyz="0 -0.028 0.0194936" rpy="1.5708 1.5708 0"/>
    <parent link="jaw_l"/>
    <child link="closing_left_2"/>
    <axis xyz="0 0 0"/>
  </joint>
  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
  <joint name="jaw_left" type="prismatic">
    <origin xyz="0 -0.06 -0" rpy="0 -0 0"/>
    <parent link="wrist"/>
    <child link="jaw_l"/>
    <axis xyz="0 0 1"/>
    <limit effort="0" velocity="0" lower="-0.00752987" upper="0.016454"/>
  </joint>
  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
  <link name="jaw_r">
    <inertial>
      <origin xyz="0 0 0" rpy="0 0 0"/>
      <mass value="0"/>
      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
    </inertial>
    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
  </link>
  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
  <link name="closing_right_2">
    <origin xyz="0 0 0" rpy="0 -0 0"/>
    <inertial>
      <origin xyz="0 0 0" rpy="0 0 0"/>
      <mass value="0"/>
      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
    </inertial>
  </link>
  <joint name="closing_right_2_frame" type="fixed">
    <origin xyz="0 -0.028 -0.0194936" rpy="1.5708 1.5708 0"/>
    <parent link="jaw_r"/>
    <child link="closing_right_2"/>
    <axis xyz="0 0 0"/>
  </joint>
  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
  <joint name="jaw_right" type="prismatic">
    <origin xyz="0 -0.06 -0" rpy="0 -0 0"/>
    <parent link="wrist"/>
    <child link="jaw_r"/>
    <axis xyz="0 0 1"/>
    <limit effort="0" velocity="0" lower="-0.016454" upper="0.00752987"/>
  </joint>
  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
  <link name="camera_mount">
    <inertial>
      <origin xyz="0 0 0" rpy="0 0 0"/>
      <mass value="0"/>
      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
    </inertial>
    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
  </link>
  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
  <link name="camera_body">
    <inertial>
      <origin xyz="0 0 0" rpy="0 0 0"/>
      <mass value="0"/>
      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
    </inertial>
    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
  </link>
  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
  <joint name="camera_body_fixed" type="fixed">
    <origin xyz="-0 -0.0321 -0.05715" rpy="0 0 -0"/>
    <parent link="camera_mount"/>
    <child link="camera_body"/>
    <axis xyz="0 0 1"/>
    <limit effort="0" velocity="0"/>
  </joint>
  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
  <joint name="camera_mount_fixed" type="fixed">
    <origin xyz="-0.03525 -0.06 -0" rpy="-0 1.5708 0"/>
    <parent link="wrist"/>
    <child link="camera_mount"/>
    <axis xyz="0 0 1"/>
    <limit effort="0" velocity="0"/>
  </joint>
  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
  <joint name="joint4_wrist" type="revolute">
    <origin xyz="-0 -0.0901 0" rpy="-0 0 -0"/>
    <parent link="forearm"/>
    <child link="wrist"/>
    <axis xyz="0 0 1"/>
    <limit effort="0" velocity="0" lower="-1.91986" upper="2.40855"/>
  </joint>
  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
  <joint name="joint3_elbow" type="revolute">
    <origin xyz="0.1083 -0.0148 0" rpy="-3.14159 0 -3.14159"/>
    <parent link="upper_arm"/>
    <child link="forearm"/>
    <axis xyz="0 0 1"/>
    <limit effort="0" velocity="0" lower="-3.141592653589793" upper="3.141592653589793"/>
  </joint>
  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
  <joint name="joint2_shoulder" type="revolute">
    <origin xyz="-0.0002 0 -0.0363" rpy="0 1.5708 0"/>
    <parent link="shoulder_yaw"/>
    <child link="upper_arm"/>
    <axis xyz="0 0 1"/>
    <limit effort="0" velocity="0" lower="-3.141592653589793" upper="3.141592653589793"/>
  </joint>
  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
  <joint name="joint1_yaw" type="revolute">
    <origin xyz="0 0 0.02" rpy="3.14159 -0 0"/>
    <parent link="base_link"/>
    <child link="shoulder_yaw"/>
    <axis xyz="0 0 1"/>
    <limit effort="0" velocity="0" lower="-3.141592653589793" upper="3.141592653589793"/>
  </joint>
</robot>

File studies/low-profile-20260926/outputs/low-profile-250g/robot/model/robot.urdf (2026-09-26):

<?xml version='1.0' encoding='utf-8'?>
<robot name="low_cost_robot_d405_low_profile">
  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
  <link name="base_link">
    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
  </link>
  <link name="shoulder_yaw">
    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
  </link>
  <link name="upper_arm">
    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
  </link>
  <link name="forearm">
    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
  </link>
  <link name="wrist">
    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
  </link>
  <link name="gripper_crank">
    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
  </link>
  <link name="jaw_l">
    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
  </link>
  <link name="jaw_r">
    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
  </link>
  <link name="coupler_l">
    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
  </link>
  <link name="coupler_r">
    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
  </link>
  <link name="camera_mount">
    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
  </link>
  <link name="camera_body">
    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
  </link>
  <link name="closing_left_1" />
  <link name="closing_left_2" />
  <link name="closing_right_1" />
  <link name="closing_right_2" />
  <joint name="joint1_yaw" type="revolute">
    <parent link="base_link" />
    <child link="shoulder_yaw" />
    <origin xyz="0 0 0.02" rpy="0 0 0" />
    <axis xyz="-0 -0 -1" />
    <limit lower="-3.1415926535897931" upper="3.1415926535897931" effort="0" velocity="0" />
  </joint>
  <joint name="joint2_shoulder" type="revolute">
    <parent link="shoulder_yaw" />
    <child link="upper_arm" />
    <origin xyz="-0.00020000000000000001 0 0.036299999999999999" rpy="0 0 0" />
    <axis xyz="1 -0 -2.2204460492503131e-16" />
    <limit lower="-3.1415926535897931" upper="3.1415926535897931" effort="0" velocity="0" />
  </joint>
  <joint name="joint3_elbow" type="revolute">
    <parent link="upper_arm" />
    <child link="forearm" />
    <origin xyz="0 0.014800000000000001 0.10830000000000001" rpy="0 0 0" />
    <axis xyz="-1 -0 -2.2204460492503131e-16" />
    <limit lower="-3.1415926535897931" upper="3.1415926535897931" effort="0" velocity="0" />
  </joint>
  <joint name="joint4_wrist" type="revolute">
    <parent link="forearm" />
    <child link="wrist" />
    <origin xyz="0 0.090100000000000013 0" rpy="0 0 0" />
    <axis xyz="-1 -0 -2.2204460492503131e-16" />
    <limit lower="-1.7802358370342162" upper="2.1642082724729685" effort="0" velocity="0" />
  </joint>
  <joint name="gripper_drive" type="revolute">
    <parent link="wrist" />
    <child link="gripper_crank" />
    <origin xyz="0 0.060000000000000012 0" rpy="0 0 0" />
    <axis xyz="-0 -1 -2.2204460492503131e-16" />
    <limit lower="-0.78539816339744828" upper="1.1344640137963142" effort="0" velocity="0" />
  </joint>
  <joint name="jaw_left" type="prismatic">
    <parent link="wrist" />
    <child link="jaw_l" />
    <origin xyz="0 0.060000000000000012 0" rpy="0 0 0" />
    <axis xyz="-1 -0 -2.2204460492503131e-16" />
    <limit lower="-0.0075298725171541432" upper="0.016453980543899453" effort="0" velocity="0" />
  </joint>
  <joint name="jaw_right" type="prismatic">
    <parent link="wrist" />
    <child link="jaw_r" />
    <origin xyz="0 0.060000000000000012 0" rpy="0 0 0" />
    <axis xyz="-1 -0 -2.2204460492503131e-16" />
    <limit lower="-0.016453980543899453" upper="0.0075298725171541432" effort="0" velocity="0" />
  </joint>
  <joint name="coupler_left" type="revolute">
    <parent link="gripper_crank" />
    <child link="coupler_l" />
    <origin xyz="0 0 0.013999999999999985" rpy="0 0 0" />
    <axis xyz="-0 -1 -2.2204460492503131e-16" />
    <limit lower="-3.1415926535897931" upper="3.1415926535897931" effort="0" velocity="0" />
  </joint>
  <joint name="coupler_right" type="revolute">
    <parent link="gripper_crank" />
    <child link="coupler_r" />
    <origin xyz="0 0 -0.014000000000000012" rpy="0 0 0" />
    <axis xyz="-0 -1 -2.2204460492503131e-16" />
    <limit lower="-3.1415926535897931" upper="3.1415926535897931" effort="0" velocity="0" />
  </joint>
  <joint name="camera_mount_fixed" type="fixed">
    <parent link="wrist" />
    <child link="camera_mount" />
    <origin xyz="0 0.060000000000000012 0.035250000000000004" rpy="0 0 0" />
  </joint>
  <joint name="camera_body_fixed" type="fixed">
    <parent link="camera_mount" />
    <child link="camera_body" />
    <origin xyz="0 9.9999999999988987e-05 0.035149999999999987" rpy="0 0 0" />
  </joint>
  <joint name="closing_left_1_fixed" type="fixed">
    <parent link="coupler_l" />
    <child link="closing_left_1" />
    <origin xyz="-0.019493588689617928 0.027999999999999997 -0.013999999999999985" rpy="0 0 0" />
  </joint>
  <joint name="closing_left_2_fixed" type="fixed">
    <parent link="jaw_l" />
    <child link="closing_left_2" />
    <origin xyz="-0.019493588689617928 0.027999999999999997 0" rpy="0 0 0" />
  </joint>
  <joint name="closing_right_1_fixed" type="fixed">
    <parent link="coupler_r" />
    <child link="closing_right_1" />
    <origin xyz="0.019493588689617924 0.027999999999999997 0.014000000000000012" rpy="0 0 0" />
  </joint>
  <joint name="closing_right_2_fixed" type="fixed">
    <parent link="jaw_r" />
    <child link="closing_right_2" />
    <origin xyz="0.019493588689617924 0.027999999999999997 0" rpy="0 0 0" />
  </joint>
</robot>

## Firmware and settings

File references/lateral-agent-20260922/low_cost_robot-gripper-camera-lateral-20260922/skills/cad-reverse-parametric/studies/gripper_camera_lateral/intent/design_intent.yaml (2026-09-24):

revision: 20260922-r1
status: geometry_review_prototype_not_fabrication_approved
objective:
  - Add an interchangeable wrist-camera mount.
  - Open jaws left/right in the assumed camera image.
  - Retain the existing fixed-plus-rotating-jaw mechanism, not a parallel-jaw redesign.
baseline: follower_geometry_revision_mixed_servos
units: mm
preserve:
  protected_tree: hardware/
  original_shape_instances: all_161_mixed_baseline_leaf_occurrences
  mechanism: fixed_jaw_plus_one_rotating_jaw
  upstream_transforms: unchanged_from_mixed_baseline
  source_of_truth: imported_BRep
change_mask:
  assembly_occurrences: '/gripper v9:1/**'
  operation: rigid_module_clocking_and_axial_spacer
  axis_in_original_static_frame: [0, 1, 0]
  axis_point_mm: [0.750000268220905, -19.999999791407, 14.75]
  angle_deg: 90
  translation_along_axis_mm: 4
  local_shape_edits_to_original_parts: none
  additional_solids:
    - wrist_camera_bridge
    - uvc28_camera_carrier
    - uvc28_pcb_spacer_4mm
new_features:
  wrist_flange:
    purpose: bolt_to_existing_90_degree_symmetric_four_hole_wrist_interface
    thickness_mm: 4
    radial_hole_pattern_mm: 6
    clearance_diameter_mm: 2.3
    thread_specification: unverified
  detachable_carrier:
    purpose: exchange_camera_specific_carrier_without_remaking_bridge
    two_hole_pitch_mm: 24
    clearance_diameter_mm: 3.2
  camera_interface:
    reference: Robonine_SO_ARM100_101_assembly_guide_step_9
    four_hole_pitch_mm: [28, 28]
    pcb_and_lens_envelopes: assumptions_not_manufacturer_CAD
  cable_tie_windows:
    purpose: proposed_strain_relief_attachment
    real_harness_sweep: not_verified
motion:
  hinge_axis_H: [0, 0, 1]
  pivot_H_mm: [8.150000268220927, -6.849999475307118, 3.4]
  reviewed_opening_deg: [0, 50]
  mathematical_rotation_sign: negative_about_positive_Z
  collision_sample_deg: 5
  vision_sample_deg: 1
acceptance_gates:
  - protected_input_hashes_unchanged
  - original_BRep_direct_reuse_and_STEP_roundtrip_comparison
  - bijective_hole_axis_matching_and_material_checks
  - no_external_intersection_in_reimported_reference_and_open_assembly
  - no_external_intersection_at_sampled_gripper_angles
  - new_mount_continuous_AABB_separation_bound
  - assumed_pinhole_visibility_including_first_hit_self_occlusion
  - valid_single_solid_STEP_and_closed_STL_for_new_parts
non_geometric_blockers:
  - actual_camera_FOV_focus_distortion_PCB_USB_and_component_measurements
  - actual_wrist_threads_fasteners_tools_and_assembly_sequence
  - print_material_orientation_strength_stiffness_and_payload
  - all_arm_joints_and_harness_motion
  - physical_fit_and_calibration
fabrication_gate: always_closed_until_a_separately_reviewed_engineering_revision

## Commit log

2026-09-24 feat: add gripper CAD project and ID5 camera handoff
    [000_DC11_A01_DUMMY_1.step, 001__0_1_1_5_.step, 002__0_1_1_6_.step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]
2026-09-24 feat(camera): D405 overhead camera mount R5 (65 deg) with review baselines
    Squash of eight commits:
    - feat(camera): ID5 case-top anchor and corner mount candidate r4 (Codex session)
    - feat(skills): add fdm-plate-layout skill
    - chore(references): add lateral review emergency idler note
    (machine-specific absolute path in the reproduce block made repo-relative)
    - chore(camera): import R4-C2 overhead mount from the external-agent package
    ID5-CAM-R4-C2 (archive SHA-256 f2c6b7b30995ea9afb2c8b33b7bea4fbb7626f397f37921201a6b6f6a4c4925e)
    - style(camera): behavior-preserving lint fixes for the R4-C2 import
    - feat(camera): D405 overhead mount R5 at 65 deg
    - fix(camera): measure ID5 case-top holes f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
2026-09-25 perf(tests): profile-driven speedup, 14m06s -> 5m28s sequential (#2)
    Squash of four commits (PR #2):
    - perf(tests): content-addressed STEP row cache for repeated parses
    (scripts/step_cache.py; SHA-256 + kernel-version key, opt-in via
    CAD_STEP_CACHE_DIR set by conftest; no mesh stored; digest-verified,
    self-repairing; assembly_io.py unchanged). 35 MB STEP: 10-22 s -> 0.33 s.
    - perf(clearance): certify only uncovered remainders; reuse fixed-shape distance
    (certify_interval checks 127 -> 63 on guide relief, same Lipschitz bound;
    DistanceTo 244 -> 108 ms/call with identical values).
    - perf(pivot): measure host-link clearance in the link frame
    (rigid invariance under the existing kine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
2026-09-25 docs(bom): fastener tables for gripper, D405 camera mount and arm (#3)
    docs/FASTENER_BOM.md lists screws, nuts and washers per part for the current
    ID5-only PG3 + D405 R5 camera mount + arm R3 (ID1-5), one unit.
    - Gripper and camera quantities are counted from the PG3_* / CAM5_* fastener
    occurrences in the saved R5 assembly; specs from pg3_candidate_bom.yaml and
    camera_overhead_d405_r5.py.
    - The arm CAD models no link screws, so scripts/survey_arm_fastener_sites.py
    counts sites where link bores are coaxial with servo bores (52 sites:
    28 M2 horn/idler, 16 M2.6 tapping into 2.1 pilots, 8 case-cover
    replacements with unresolved spec), plus 3 HN11-I101 idler sets.
    - Screw lengths are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
2026-09-26 feat(studies): archive low-profile D405 integration (#4)
    Import the reviewed D405 low-profile design and Onshape work with rebuild and conversion evidence. Add a manifest verifier, reproducibility notes, handoffs, and repository navigation.
    Validation: imported manifest verifier passes all 693 files; converter tests (13), intake verifier tests (52), and CAD tests (20) passed. The full repository suite could not complete here: VTK render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
    [CAM5_BASE.step, CAM5_BASE.stl, CAM5_D405_CARRIER.step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]
2026-10-03 fix(cad): widen P05 connector windows and archive assembly manual
    - Replace only P05 in a copied frozen V2 with 5.5 x 10.2 mm R0.5 windows.
    Retain original holes, actual motor seating patches and all 262 occurrences.
    - Diagnose nominal connector passage before motor insertion separately from
    installed-motor access. Retain rear-cover FAIL and supplier ERROR/UNKNOWN.
    - Archive reviewed STEP/STL, Chili3D views, hashes, 10-step Japanese manual
    with bolt lengths/counts and five reviews, and the project-local skill.
    Validation: 23 targeted tests pass; Ruff check/format and skill validation pass.
    Saved-artifact controls, browser hashes and manual rendering checks pass.
    Physical assembly, pre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
    [P05_CABLE_CLEARANCE_CANDIDATE.step, P05_CABLE_CLEARANCE_CANDIDATE.stl, plug-with-motor-diagnostic.json]
